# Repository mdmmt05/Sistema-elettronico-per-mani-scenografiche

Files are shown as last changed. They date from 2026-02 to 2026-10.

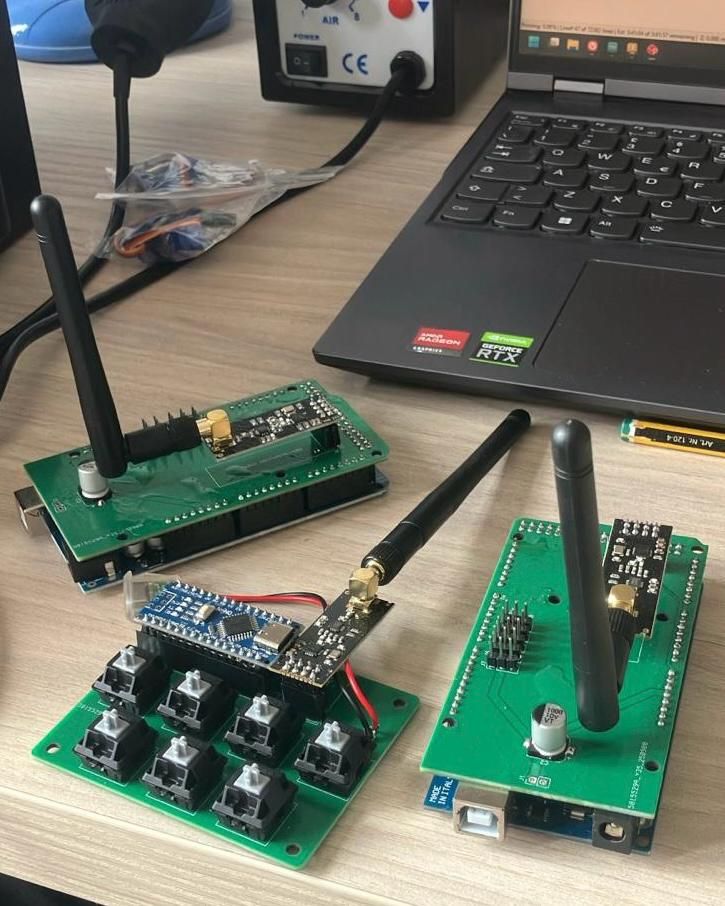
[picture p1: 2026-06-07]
1771791220092.jpeg

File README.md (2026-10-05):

# Nato Due Volte — Scenic Robotic Hands Control System

<div align="center">







</div>

> 🇮🇹 [Italiano](#italiano) · 🇬🇧 [English](#english)

---

# Italiano

## Descrizione

**Nato Due Volte** è un carro carnevalesco presentato alla **73ª edizione del Carnevale di Massafra**. Questa repository documenta il sistema elettronico e firmware realizzato per controllare due **mani scenografiche robotizzate**, ciascuna dotata di cinque dita mosse indipendentemente da servomotori.

Il sistema utilizza un **telecomando palmare personalizzato** che comunica via radio con due unità di controllo indipendenti, una per mano. Ogni unità è basata su Arduino Mega 2560 e su una shield progettata su misura; il telecomando è basato su Arduino Nano con una propria shield dedicata.

## Stato e validazione

Questo progetto è stato **progettato, costruito, programmato, integrato e collaudato fisicamente** per l'impiego sul carro.

A differenza di altri repository presenti nel profilo, la progettazione elettronica, il firmware e l'integrazione sono stati svolti **prevalentemente direttamente dall'autore**, con un approccio hands-on. Il sistema è stato inoltre testato in condizioni operative reali.

Il progetto rappresenta quindi uno dei lavori più direttamente indicativi delle competenze pratiche dell'autore in elettronica embedded, PCB, integrazione hardware-software e collaudo.

## Obiettivi progettuali

I requisiti principali erano:

- controllo indipendente di due mani;
- cinque servomotori per mano;
- comando wireless affidabile;
- interfaccia semplice per un operatore non tecnico;
- installazione e manutenzione semplici durante l'allestimento del carro;
- alimentazione separata e adeguata al carico dei servomotori;
- possibilità di selezionare più sequenze/movimenti per ciascuna mano.

## Architettura

```mermaid
flowchart LR
    OP[Operatore] --> REMOTE[Telecomando
Arduino Nano]
    REMOTE -->|nRF24L01+| CTRL1[Controller mano 1
Arduino Mega]
    REMOTE -->|nRF24L01+| CTRL2[Controller mano 2
Arduino Mega]
    CTRL1 --> S1[5 servomotori]
    CTRL2 --> S2[5 servomotori]
```

Il telecomando consente di inviare fino a **7 comandi di movimento** a ciascuna mano mediante combinazioni di pulsanti.

## Hardware

| Componente | Quantità | Funzione |
|---|---:|---|
| Arduino Mega 2560 | 2 | Unità di controllo delle mani |
| Arduino Nano | 1 | Telecomando |
| nRF24L01+ | 3 | Comunicazione radio |
| Shield personalizzata Mega | 2 | RF, connettori e distribuzione segnali |
| Shield personalizzata Nano | 1 | Pulsanti e modulo RF |
| Servomotori | 10 | Attuazione delle dita |
| Alimentatore 5 V / min. 8 A | 2 | Alimentazione delle mani |
| Powerbank 5 V | 1 | Alimentazione telecomando |

### Collegamento servomotori

| Connettore | Indice firmware | Dito |
|---|---:|---|
| J3 | 0 | Pollice |
| J4 | 1 | Indice |
| J5 | 2 | Medio |
| J6 | 3 | Anulare |
| J7 | 4 | Mignolo |

## Repository

```text
nato-due-volte/
├── controller_code.ino
├── code_telecomando.ino
└── manuale_di_installazione.docx
```

## Installazione firmware

Prerequisiti:

- Arduino IDE;
- libreria RF24.

Per ogni Arduino Mega, impostare `USE_FIRST` in modo coerente con il controller da programmare, quindi caricare `controller_code.ino`. Caricare `code_telecomando.ino` sull'Arduino Nano.

> Caricare entrambe le unità con la stessa configurazione può far rispondere entrambe le mani allo stesso comando.

Per cablaggio, alimentazione e troubleshooting fare riferimento al manuale di installazione.

## Demo

I video `natoduevolte.mp4` e `mano.mp4` mostrano il sistema fisico in funzione.

---

# English

## Project description

**Nato Due Volte** (*Born Twice*) was a carnival float presented at the **73rd edition of the Carnevale di Massafra**. This repository documents the electronics and firmware built to control two **scenic robotic hands**, each with five independently actuated servo-driven fingers.

A custom handheld remote communicates by RF with two independent control units, one for each hand. Each hand controller uses an Arduino Mega 2560 and a custom shield, while the remote uses an Arduino Nano with its own custom shield.

## Status and validation

This project was **designed, built, programmed, integrated, and physically tested** for use on the float.

Unlike some other repositories in this profile, the electronics design, firmware implementation, and system integration were performed **primarily directly by the author** through a hands-on development process. The finished system was tested in real operating conditions.

For that reason, this repository is one of the most representative examples of the author's practical work in embedded electronics, PCB design, hardware-software integration, and field testing.

## Design requirements

The main requirements were:

- independent control of two hands;
- five servos per hand;
- reliable wireless operation;
- simple interaction for a non-technical operator;
- straightforward installation and maintenance;
- adequate power delivery for the servo load;
- multiple selectable motion commands for each hand.

## Architecture

```mermaid
flowchart LR
    OP[Operator] --> REMOTE[Handheld remote
Arduino Nano]
    REMOTE -->|nRF24L01+| CTRL1[Hand controller 1
Arduino Mega]
    REMOTE -->|nRF24L01+| CTRL2[Hand controller 2
Arduino Mega]
    CTRL1 --> S1[5 servos]
    CTRL2 --> S2[5 servos]
```

The remote can send up to **7 motion commands** to each hand through button combinations.

## Hardware

| Component | Qty | Purpose |
|---|---:|---|
| Arduino Mega 2560 | 2 | Hand control units |
| Arduino Nano | 1 | Handheld remote |
| nRF24L01+ | 3 | RF communication |
| Custom Mega shield | 2 | RF and servo interfacing |
| Custom Nano shield | 1 | Buttons and RF interface |
| Servo motors | 10 | Finger actuation |
| 5 V / min. 8 A PSU | 2 | Hand power supply |
| 5 V power bank | 1 | Remote power supply |

## Repository structure

```text
nato-due-volte/
├── controller_code.ino
├── code_telecomando.ino
└── manuale_di_installazione.docx
```

## Firmware installation

Requirements:

- Arduino IDE;
- RF24 library.

Configure `USE_FIRST` appropriately for each Mega controller before uploading `controller_code.ino`. Upload `code_telecomando.ino` to the Arduino Nano.

For wiring, power-supply details, and troubleshooting, see the installation manual.

## Demo

The files `natoduevolte.mp4` and `mano.mp4` show the physical system in operation.

## License

MIT License. See `LICENSE`.

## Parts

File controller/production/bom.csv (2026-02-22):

Designator | Footprint | Quantity | Value | LCSC Part #
A1 | Arduino_Mega2560_R3_Shield | 1 | Arduino_Mega2560_R3_Shield
C1 | 0402 | 1 | 10uF
C2 | CP_Elec_8x10.5 | 1 | 1000uF
C3 | 0402 | 1 | 100nF
J1 | PinHeader_1x02_P2.54mm_Vertical | 1 | PW
J3 | PinHeader_1x03_P2.54mm_Vertical | 1 | Servo1
J4 | PinHeader_1x03_P2.54mm_Vertical | 1 | Servo2
J5 | PinHeader_1x03_P2.54mm_Vertical | 1 | Servo3
J6 | PinHeader_1x03_P2.54mm_Vertical | 1 | Servo4
J7 | PinHeader_1x03_P2.54mm_Vertical | 1 | Servo5
J8 | PinHeader_2x04_P2.54mm_Vertical | 1 | Radio

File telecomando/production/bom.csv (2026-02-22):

Designator | Footprint | Quantity | Value | LCSC Part #
A1 | Arduino_Nano | 1 | Arduino_Nano_v3.x
C1 | 0402 | 1 | 10uF
C2 | 0402 | 1 | 100nF
J1 | PinHeader_1x02_P2.54mm_Vertical | 1 | P_IN
J8 | PinHeader_2x04_P2.54mm_Vertical | 1 | Radio
R3, R4, R5, R6, R7, R8, R9 | 0402 | 7 | 10k
SW1, SW2, SW3, SW4, SW5, SW6, SW7 | SW_Cherry_MX_1.00u_PCB | 7 | SW_Push

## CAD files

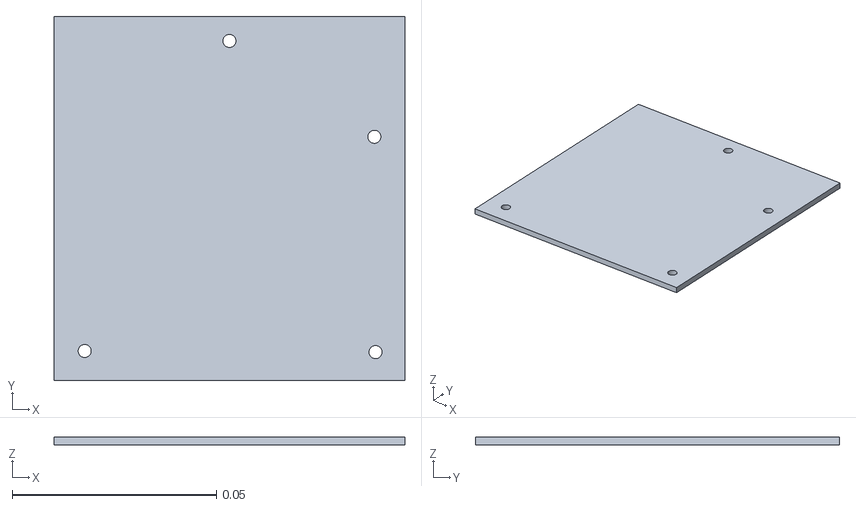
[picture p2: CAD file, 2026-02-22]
telecomando/base.stl
0.086 x 0.0892 x 0.002

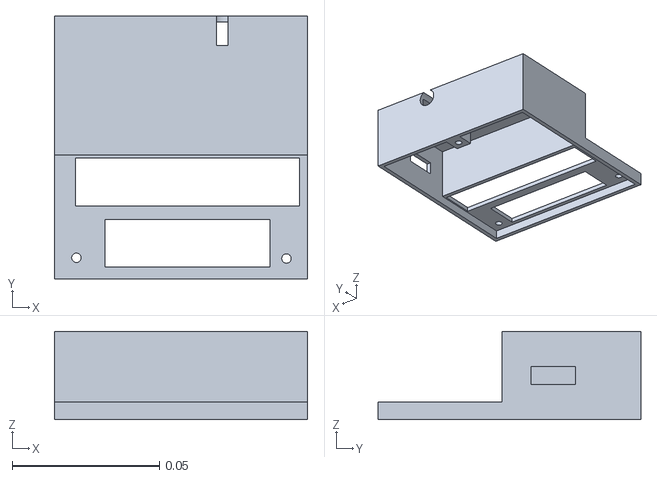
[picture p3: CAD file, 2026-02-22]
telecomando/coperchio.stl
0.086 x 0.0892 x 0.03

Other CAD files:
controller/supporto.ipt
telecomando/Solido1.ipt
telecomando/Solido2.ipt
telecomando/telecomando.iam

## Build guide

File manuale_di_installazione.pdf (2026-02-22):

NATO DUE VOLTE — Installation Manual · Page 1 of 14

# NATO DUE VOLTE

## 73ª edizione del Carnevale di Massafra

# Manuale di Installazione

## Installation Manual

Sistema di controllo delle mani scenografiche robotizzate Robotic Hand Control System

Versione 1.0 · 2025
github.com/mdmmt05/Sistema-elettronico-per-mani-scenografiche

— ITALIANO —

### 1. Introduzione

Il presente documento descrive le istruzioni di installazione e configurazione del sistema di controllo delle mani scenografiche sviluppato per il carro “Nato Due Volte”, presentato alla 73ª edizione del Carnevale di Massafra (Ass. Crazy Events).

Il sistema è composto da due mani scenografiche robotizzate, ciascuna dotata di cinque dita ad attuazione indipendente. Le mani sono gestite da due unità di controllo dedicate e comandate in modalità wireless tramite un telecomando palmare personalizzato.

### 1.1 Panoramica del sistema

Progetto | Nato Due Volte — 73ª edizione Carnevale di Massafra
Sistema | Controllo wireless di mani robotizzate
Unità di controllo | 2 × Arduino Mega 2560 su shield personalizzata
Telecomando | 1 × Arduino Nano su shield personalizzata
Modulo RF | nRF24L01PA+LNA (2,4 GHz, 250 kbps, canale 110)
Attuatori | 5 servomotori per mano (10 in totale)
Firmware | controller_code.ino / code_telecomando.ino

### 1.2 Prerequisiti

Software
- Arduino IDE (qualsiasi versione recente)
- Libreria RF24 — installabile tramite il Library Manager dell’Arduino IDE

Hardware
- 2 × unità di controllo (Arduino Mega + shield personalizzata + nRF24L01+)
- 1 × telecomando (Arduino Nano + shield personalizzata + nRF24L01+)
- 10 × servomotori (5 per mano), con connettore a tre fili (DATA / 5 V / GND)
- 1 × alimentatore regolato 5 V, minimo 5 A, per ciascuna unità di controllo
- 1 × alimentatore regolato 5 V (es. powerbank) per il telecomando

### 2. Telecomando

Il telecomando è il dispositivo diverso dagli altri due nella dotazione. Ospita un Arduino Nano su una shield personalizzata e dispone di sette pulsanti per l’invio dei comandi di movimento alle due unità di controllo.

### 2.1 Identificazione

Il telecomando si identifica come il dispositivo morfologicamente diverso rispetto alle due unità di controllo. Espone una porta USB-C sul lato, utilizzata per l’alimentazione.

### 2.2 Alimentazione

Il telecomando deve essere alimentato tramite la porta USB-C con una sorgente regolata a 5 V (es. powerbank).

⚠ WARNING: Non utilizzare mai una sorgente di alimentazione al di fuori dell’intervallo 4,8 V – 5,2 V. Tensioni superiori a questo limite possono danneggiare irreversibilmente la scheda.

L’alimentazione corretta è confermata dall’accensione di un LED verde in prossimità della porta USB-C.

### 2.3 Layout e indirizzamento dei pulsanti

I sette pulsanti sono indicizzati in ordine di lettura (da sinistra a destra, dall’alto verso il basso), a partire da 0:

[ 0 ] | [ 1 ] | [ 2 ] | [ 3 ]
[ 4 ] | [ 5 ] | [ 6 ]

### 2.4 Protocollo di comunicazione

Un comando viene trasmesso tramite una sequenza di due pressioni:

- La prima pressione seleziona l’indice del comando per il controller #1.
- La seconda pressione seleziona l’indice del comando per il controller #2.
- Le due pressioni devono avvenire entro una finestra di timeout di 2 secondi; se il timeout scade, la sequenza si azzera e la prima pressione deve essere ripetuta.
Il payload trasmesso via radio è una stringa nel formato “primoIndice,secondoIndice” (es. “2,5”). Ciascun controller estrae solo il valore di propria competenza in base al flag USE_FIRST nel proprio firmware (vedere Sezione 4.2).

### 2.5 Antenna RF

L’antenna del telecomando dovrebbe essere orientata verso le unità di controllo per ottimizzare la qualità del segnale. In pratica, grazie alla configurazione radio resistente ai disturbi, un puntamento preciso non è strettamente necessario. La latenza massima attesa tra l’invio del comando e la sua esecuzione sulle unità di controllo è di 75 ms. Ritardi superiori indicano con alta probabilità una trasmissione fallita; in tal caso è sufficiente reinviare il comando.

### 2.6 Smontaggio (se necessario)

Lo smontaggio del telecomando è necessario solo qualora la scheda Arduino Nano interna debba essere riprogrammata.

⚠ WARNING: Devono essere svitate esclusivamente le due viti piccole (M2). La vite più grande è una vite di registro che consente alla piastra inferiore di ruotare attorno al proprio asse per accedere al vano interno — non va rimossa.

### 3. Unità di Controllo (Mani)

Le due unità di controllo sono assiemi identici, ciascuno costituito da un Arduino Mega 2560 montato su una shield personalizzata. Ogni unità aziona una mano robotizzata tramite cinque servomotori e riceve i comandi wireless dal telecomando.

### 3.1 Alimentazione

Ciascuna unità di controllo è alimentata tramite il connettore contrassegnato J1 sulla shield personalizzata. Tale connettore si trova in prossimità del condensatore elettrolitico (grosso cilindro argentato).

Connettore | J1
Pin con simbolo quadrato | GND (massa)
Altro pin | VCC (alimentazione positiva)
Tensione richiesta | 5 V regolati
Corrente minima | 5 A (per garantire sufficiente corrente a tutti e cinque i servomotori simultaneamente)

⚠ WARNING: L’utilizzo di un alimentatore con corrente insufficiente può causare comportamenti anomali dei servomotori o reset del sistema.

### 3.2 Modulo RF e antenna

Il modulo RF nRF24L01+ è montato sulla shield ed è dotato di antenna esterna. Per una ricezione ottimale, l’antenna dovrebbe essere fatta uscire dall’involucro metallico della mano.

Note: Qualora fosse necessario riposizionare l’antenna, è consigliabile spostare solo l’elemento antenna, non l’intero modulo RF, per preservare l’integrità del segnale.

### 3.3 Collegamento dei servomotori

I servomotori vanno collegati ai connettori da J3 a J7 sulla shield. L’ordine di cablaggio è indicato a lato di ciascun connettore sulla shield stessa:

DATA | — | 5 V | — | GND

L’indice del servomotore nel firmware corrisponde direttamente all’etichetta del connettore:

Connector (shield) | Servo index (firmware) | Finger
J3 | 0 | Pollice
J4 | 1 | Indice
J5 | 2 | Medio
J6 | 3 | Anulare
J7 | 4 | Mignolo

Note: L’indice 0 corrisponde al primo dito attuato (pollice); gli indici aumentano in sequenza attraverso la mano.

### 4. Software

### 4.1 Panoramica dei file

controller_code.ino | Firmware per le due unità di controllo (Arduino Mega).
code_telecomando.ino | Firmware per il telecomando (Arduino Nano).

### 4.2 Caricamento del firmware sulle unità di controllo

Entrambe le unità di controllo utilizzano lo stesso file sorgente (controller_code.ino). La costante preprocessore USE_FIRST determina quale valore della stringa di comando ricevuta ciascuna unità deve elaborare:

Controller #1 | #define USE_FIRST true
Controller #2 | #define USE_FIRST false

⚠ WARNING: Questo flag deve essere impostato correttamente prima di caricare il firmware su ciascuna scheda. Caricare entrambe le schede con lo stesso valore causerà la risposta di entrambe le mani allo stesso pulsante.

Procedura di caricamento:

- Aprire controller_code.ino nell’Arduino IDE.
- Impostare USE_FIRST con il valore appropriato per la scheda di destinazione.
- Selezionare “Arduino Mega or Mega 2560” come scheda target.
- Caricare lo sketch.
- Ripetere la procedura per la seconda scheda con il valore opposto di USE_FIRST.

### 4.3 Caricamento del firmware sul telecomando

Aprire code_telecomando.ino nell’Arduino IDE, selezionare “Arduino Nano” come scheda target e caricare lo sketch. Non è richiesta alcuna configurazione aggiuntiva.

### 4.4 Struttura della mappa dei comandi

Il firmware memorizza 7 sequenze di movimento predefinite (una per pulsante) nell’array commandMaps. Ogni comando è composto da un array ordinato di Step, un contatore numSteps e un flag repeat.

Ciascuno Step è definito dai seguenti campi:

Field | Type | Description
servoIndex | int (0–4) | Index of the servo motor to move.
targetAngle | int (°) | Target position in degrees.
time | ulong (ms) | Duration of the movement (interpolated) or minimum settling time (natural).

Field | Type | Description
pause | ulong (ms) | Delay after this step before the next begins. A non-zero value also terminates the current synchronised group.
useInterpolation | bool | true: linear interpolation over time. false: full-speed snap to target.

Gruppi sincronizzati
Gli step vengono raggruppati automaticamente dal firmware. Step consecutivi con pause == 0 vengono eseguiti in parallelo (tutti i movimenti del gruppo partono simultaneamente). Uno step con pause > 0 termina il gruppo corrente: tutti i movimenti del gruppo vengono completati, dopodiché trascorre la pausa specificata prima dell’inizio del gruppo successivo.

Modifica di un comando
Per modificare un comando esistente o aggiungerne uno nuovo, è necessario modificare la voce corrispondente in commandMaps:
- Aggiungere o rimuovere elementi Step all’interno delle parentesi graffe.
- Aggiornare il valore intero numSteps affinché corrisponda al numero effettivo di step nell’array.
- Impostare il booleano repeat a true se il comando deve ripetersi in loop fino all’arrivo di un nuovo comando, o a false per un’esecuzione singola.
- Qualsiasi comando in arrivo interrompe immediatamente quello in esecuzione.

Note: Angoli di step al di fuori dell’escursione fisica del servomotore (tipicamente 0–270°) verranno limitati dalla libreria servo. Si raccomanda di validare i nuovi movimenti a bassa velocità prima dell’utilizzo in condizioni di esibizione.

### 5. Riferimento Rapido

### 5.1 Lista di verifica pre-installazione

- Alimentatori verificati: 5 V / 5 A per ciascuna unità di controllo, 5 V per il telecomando.
- controller_code.ino caricato con USE_FIRST corretto su ciascun Mega.
- code_telecomando.ino caricato sul Nano.
- Tutti i connettori dei servomotori inseriti negli slot corretti (J3–J7).
- Antenne RF portate all’esterno degli involucri metallici.
- LED verde sul telecomando acceso all’accensione.

### 5.2 Risoluzione dei problemi

Il telecomando non si
accende

Verificare la sorgente di alimentazione USB-C. Controllare che la tensione sia compresa tra 4,8 e 5,2 V.

Comando non ricevuto dall’unità di controllo | Reinviare il comando. Assicurarsi che le due pressioni avvengano entro il timeout di 2 s. Verificare l’orientamento dell’antenna RF.
La mano sbagliata risponde a un pulsante | Verificare che USE_FIRST sia impostato correttamente su ciascuna unità di controllo e ricaricare il firmware se necessario.
Il servo si porta in posizione errata | Controllare l’orientamento del connettore del servo (DATA / 5 V / GND). Verificare l’assegnazione J3–J7.
Movimento anomalo / reset del sistema | Corrente dell’alimentatore insufficiente. Utilizzare un alimentatore con corrente minima di 8 A.
Ritardo tra pressione e movimento della mano | Atteso: fino a 75 ms. Se sistematicamente superato, verificare la presenza di interferenze RF o pressione insufficiente sui pulsanti.

— ENGLISH —

### 1. Introduction

This document provides the installation and configuration instructions for the robotic hand control system developed for the float “Nato Due Volte,” presented at the 73rd edition of the Carnevale di Massafra.

The system consists of two scenic robotic hands, each equipped with five independently actuated fingers. The hands are driven by two dedicated control units and operated wirelessly via a custom handheld remote controller.

### 1.1 System overview

Project | Nato Due Volte — 73rd Carnevale di Massafra
System | Wireless robotic hand control
Control units | 2 × Arduino Mega 2560 on custom shield
Remote | 1 × Arduino Nano on custom shield
RF module | nRF24L01+ (2.4 GHz, 250 kbps, channel 110)
Actuators | 5 servo motors per hand (10 total)
Firmware | controller_code.ino / code_telecomando.ino

### 1.2 Prerequisites

Software
- Arduino IDE (any recent version)
- RF24 library — installable via the Arduino IDE Library Manager

Hardware
- 2 × control unit assembly (Arduino Mega + custom shield + nRF24L01+)
- 1 × remote controller assembly (Arduino Nano + custom shield + nRF24L01+)
- 10 × servo motors (5 per hand), with three-wire connectors (DATA / 5 V / GND)
- 1 × regulated 5 V power supply, minimum 5 A, for each control unit
- 1 × regulated 5 V power supply (e.g. powerbank) for the remote controller

### 2. Remote Controller

The remote controller is the unique device in the kit. It hosts an Arduino Nano on a custom shield and provides seven push-buttons for sending movement commands to the two control units.

### 2.1 Identification

The remote controller can be identified as the device that differs from the other two. It exposes a USB-C port on its side, used for power supply.

### 2.2 Power supply

The remote controller must be powered via its USB-C port with a regulated 5 V source (e.g. a powerbank).

⚠ WARNING: Never use a power source outside the 4.8 V – 5.2 V range. Voltages above this threshold may permanently damage the board.

Correct power delivery is confirmed by a green LED illuminating near the USB-C port.

### 2.3 Button layout and addressing

The seven buttons are indexed in reading order (left to right, top to bottom), starting from 0:

[ 0 ] | [ 1 ] | [ 2 ] | [ 3 ]
[ 4 ] | [ 5 ] | [ 6 ]

### 2.4 Communication protocol

A command is transmitted using a two-press sequence:

- The first button press selects the command index for controller #1.
- The second button press selects the command index for controller #2.
- The two presses must occur within a 2-second timeout window; if the window expires, the sequence resets and the first press must be repeated.
The payload sent over the air is a comma-separated string of the form “firstIndex,secondIndex” (e.g. “2,5”). Each controller extracts only the value relevant to it based on the USE_FIRST flag in its firmware (see Section 4.2).

### 2.5 RF antenna

The antenna protruding from the remote controller should be oriented towards the control units for optimal signal strength. In practice, due to the noise-resistant radio configuration, precise pointing is not strictly required. A maximum latency of 75 ms is expected between command transmission and execution on the control units. Delays exceeding this threshold most likely indicate a failed transmission; the command should be resent in that case.

### 2.6 Disassembly (if required)

Disassembly of the remote controller is required only if the internal Arduino Nano board needs to be reprogrammed.

⚠ WARNING: Only the two small M2 screws must be removed. The larger screw is a pivot that allows the bottom plate to rotate and expose the internal compartment — do not unscrew it.

### 3. Control Units (Hands)

The two control units are identical assemblies, each consisting of an Arduino Mega 2560 mounted on a custom shield. Each unit drives one robotic hand via five servo motors and receives wireless commands from the remote controller.

### 3.1 Power supply

Each control unit is powered through the connector labelled J1 on the custom shield. This connector is located near the electrolytic capacitor (large silver cylindrical component).

Connector | J1
Square-marked pin | GND (ground)
Other pin | VCC (positive supply)
Required voltage | 5 V regulated
Minimum current | 5 A (to ensure adequate power to all five servo motors simultaneously)

⚠ WARNING: Using a power supply with insufficient current rating may cause erratic servo behaviour or system resets.

### 3.2 RF module and antenna

The nRF24L01+ RF module is mounted on the shield and is fitted with an external antenna. For optimal reception, the antenna should be routed outside the metallic enclosure of the hand.

Note: If repositioning of the antenna is required, only the antenna element itself should be relocated. Moving the entire RF module may compromise signal integrity.

### 3.3 Servo motor connections

Servo motors are connected to the connectors labelled J3 through J7 on the shield. The wiring order is printed on the shield next to each connector:

DATA | — | 5 V | — | GND

The servo index in the firmware corresponds directly to the connector label:

Connector (shield) | Servo index (firmware) | Finger
J3 | 0 | Thumb
J4 | 1 | Index
J5 | 2 | Middle
J6 | 3 | Ring
J7 | 4 | Little

Note: Servo index 0 corresponds to the first activated finger (thumb); indices increase sequentially across the hand.

### 4. Software

### 4.1 File overview

controller_code.ino | Firmware for the two control units (Arduino Mega).
code_telecomando.ino | Firmware for the remote controller (Arduino Nano).

### 4.2 Flashing the control units

Both control units use the same source file (controller_code.ino). The USE_FIRST preprocessor constant determines which value from the received command string each unit responds to:

Controller #1 | #define USE_FIRST true
Controller #2 | #define USE_FIRST false

⚠ WARNING: This flag must be set correctly before flashing each board. Flashing both boards with the same value will cause both hands to respond to the same button press.

To flash a control unit:

- Open controller_code.ino in the Arduino IDE.
- Set USE_FIRST to the appropriate value for the target board.
- Select “Arduino Mega or Mega 2560” as the board.
- Upload the sketch.
- Repeat for the second board with the opposite USE_FIRST value.

### 4.3 Flashing the remote controller

Open code_telecomando.ino in the Arduino IDE, select “Arduino Nano” as the board, and upload the sketch. No configuration is required.

### 4.4 Command map structure

The firmware stores 7 pre-defined movement sequences (one per button) in the commandMaps array. Each command consists of an ordered array of Steps, a step count (numSteps), and a repeat flag.

Each Step is defined by the following fields:

Field | Type | Description
servoIndex | int (0–4) | Index of the servo motor to move.
targetAngle | int (°) | Target position in degrees.
time | ulong (ms) | Duration of the movement (interpolated) or minimum settling time (natural).
pause | ulong (ms) | Delay after this step before the next begins. A non-zero value also terminates the current synchronised group.

Field | Type | Description
useInterpolation | bool | true: linear interpolation over time. false: full-speed snap to target.

Synchronised groups
Steps are grouped automatically by the firmware. Consecutive steps with pause == 0 are executed in parallel (all servo movements in the group start simultaneously). A step with pause > 0 terminates the current group, all movements in the group complete, and the specified pause elapses before the next group begins.

Modifying a command
To modify an existing command or add a new one, edit the corresponding entry in commandMaps:
- Add or remove Step entries within the braces.
- Update the numSteps integer to match the actual number of steps in the array.
- Set the repeat boolean to true if the command should loop until interrupted, or false for single execution.
- Any incoming command immediately interrupts the currently executing one.

Note: Step angles outside the physical servo range (typically 0–270°) will be clamped by the servo library. Validate new movements at low speed before use in performance conditions.

### 5. Quick Reference

### 5.1 Pre-installation checklist

- Power supplies verified: 5 V / 5 A for each control unit, 5 V for remote.
- controller_code.ino flashed with correct USE_FIRST on each Mega.
- code_telecomando.ino flashed on the Nano.
- All servo connectors inserted in correct J3–J7 slots.
- RF antennas routed outside metallic enclosures.
- Green LED on remote controller illuminated at power-on.

### 5.2 Troubleshooting

Remote controller does
not power on

Check USB-C power source. Verify voltage is within 4.8– 5.2 V.

Command not received by control unit | Re-send the command. Ensure both button presses occur within the 2 s timeout. Check RF antenna orientation.
Wrong hand responds to a button | Verify USE_FIRST is set correctly on each control unit and re-flash if necessary.
Servo moves to incorrect position | Check servo connector orientation (DATA / 5 V / GND). Verify J3–J7 assignment.
Erratic servo movement / system resets | Insufficient power supply current. Use a supply rated at a minimum of 5 A.
Latency between press and hand movement | Expected: up to 75 ms. If consistently exceeded, check for RF interference or insufficient button press duration.

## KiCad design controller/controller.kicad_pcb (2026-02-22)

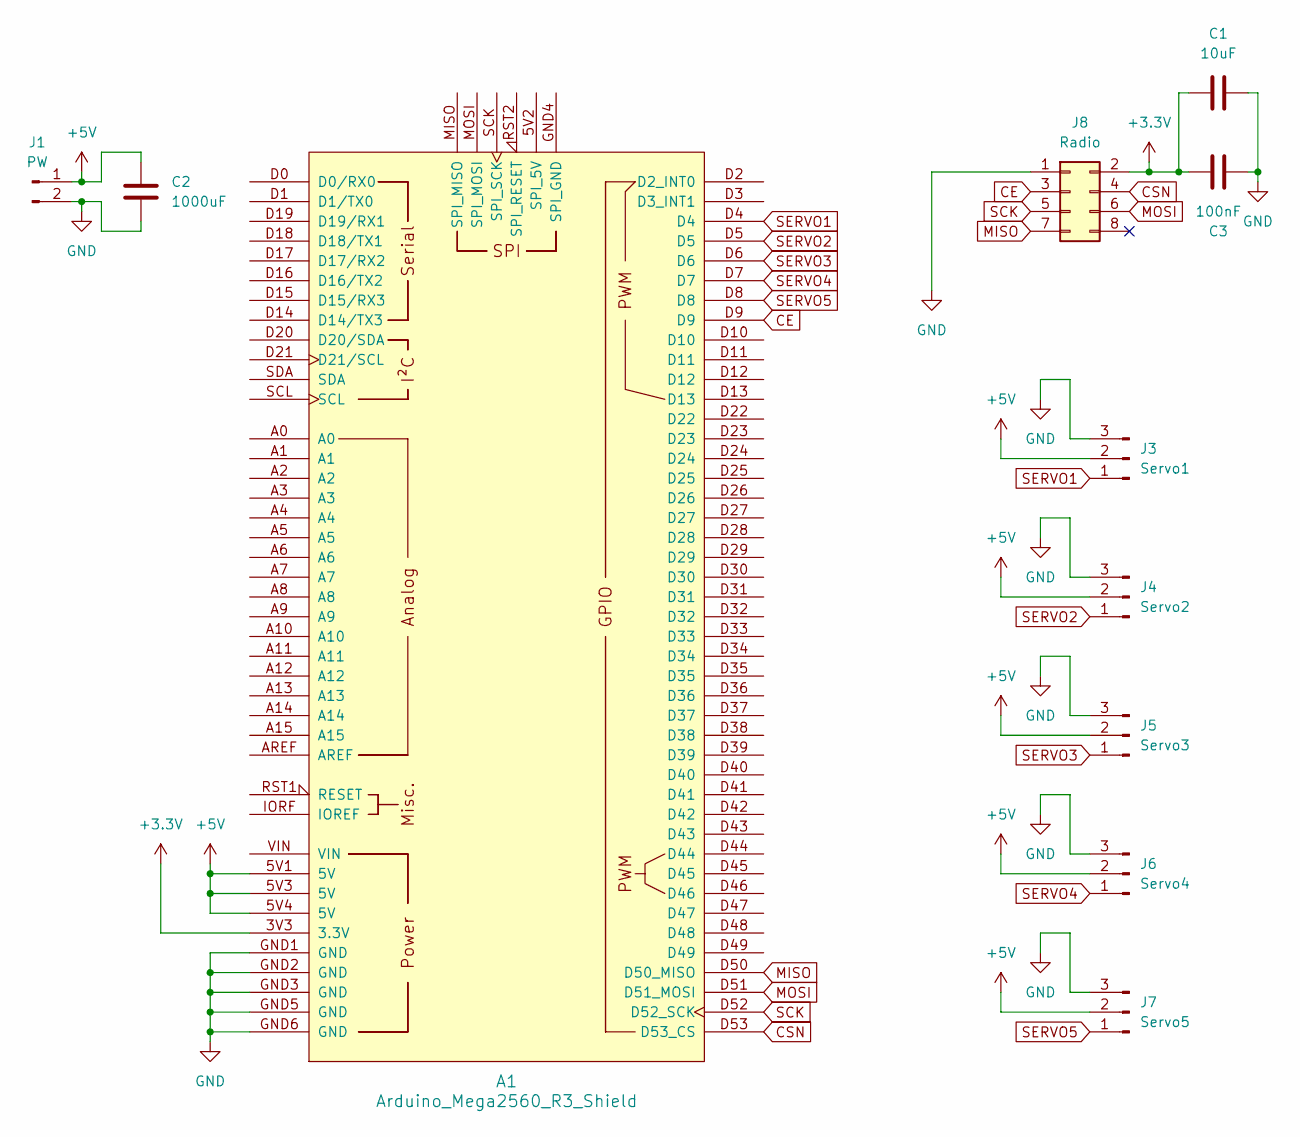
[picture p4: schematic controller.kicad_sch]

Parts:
A1: Arduino_Mega2560_R3_Shield
C1: 10uF; C_0402_1005Metric_Pad0.74x0.62mm_HandSolder
C2: 1000uF; CP_Elec_8x10.5
C3: 100nF; C_0402_1005Metric_Pad0.74x0.62mm_HandSolder
J1: PW; PinHeader_1x02_P2.54mm_Vertical
J3: Servo1; PinHeader_1x03_P2.54mm_Vertical
J4: Servo2; PinHeader_1x03_P2.54mm_Vertical
J5: Servo3; PinHeader_1x03_P2.54mm_Vertical
J6: Servo4; PinHeader_1x03_P2.54mm_Vertical
J7: Servo5; PinHeader_1x03_P2.54mm_Vertical
J8: Radio; PinHeader_2x04_P2.54mm_Vertical

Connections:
+3.3V: A1.3V3 (3.3V), C1.1, C3.2, J8.2
+5V: A1.5V1 (5V), A1.5V3 (5V), A1.5V4 (5V), C2.2, J1.1, J3.2, J4.2, J5.2, J6.2, J7.2
CE: A1.D9, J8.3
CSN: A1.D53 (D53_CS), J8.4
GND: A1.GND1 (GND), A1.GND2 (GND), A1.GND3 (GND), A1.GND5 (GND), A1.GND6 (GND), C1.2, C2.1, C3.1, J1.2, J3.3, J4.3, J5.3, J6.3, J7.3, J8.1
MISO: A1.D50 (D50_MISO), J8.7
MOSI: A1.D51 (D51_MOSI), J8.6
SCK: A1.D52 (D52_SCK), J8.5
SERVO1: A1.D4, J3.1
SERVO2: A1.D5, J4.1
SERVO3: A1.D6, J5.1
SERVO4: A1.D7, J6.1
SERVO5: A1.D8, J7.1

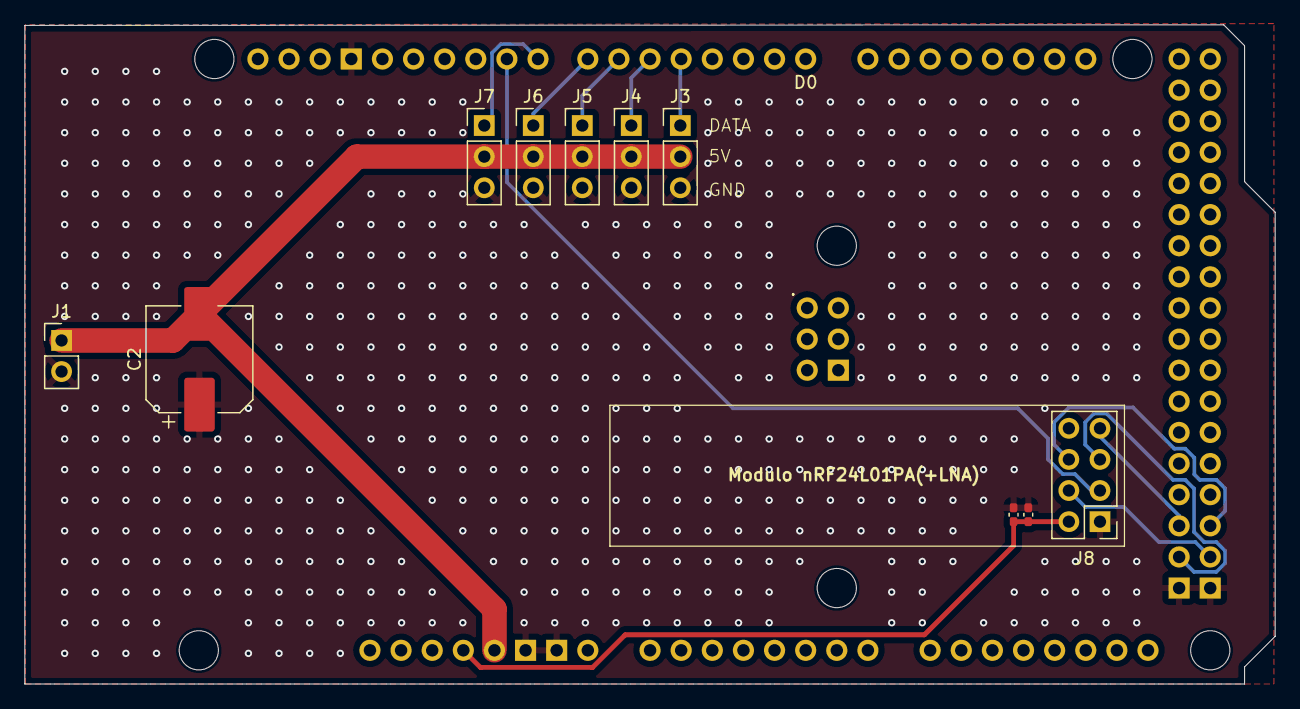
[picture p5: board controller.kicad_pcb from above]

Board: 2 copper layers, 102.1 x 53.8 mm, 11 parts (0 on the bottom side), 13 nets.

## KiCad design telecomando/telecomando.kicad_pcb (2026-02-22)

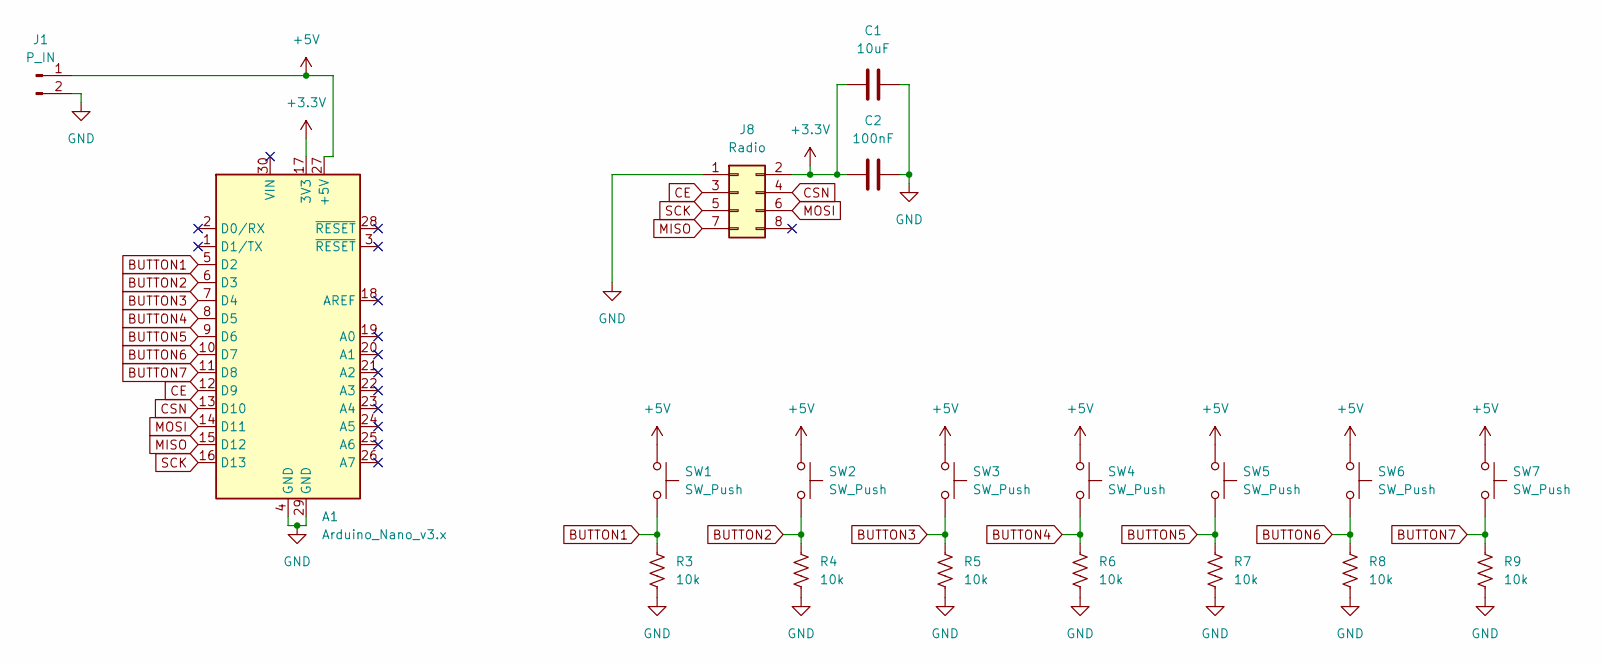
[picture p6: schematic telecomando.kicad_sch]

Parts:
A1: Arduino_Nano_v3.x; Arduino_Nano
C1: 10uF; C_0402_1005Metric_Pad0.74x0.62mm_HandSolder
C2: 100nF; C_0402_1005Metric_Pad0.74x0.62mm_HandSolder
J1: P_IN; PinHeader_1x02_P2.54mm_Vertical
J8: Radio; PinHeader_2x04_P2.54mm_Vertical
R3, R4, R5, R6, R7, R8, R9: 10k; R_0402_1005Metric_Pad0.72x0.64mm_HandSolder
SW1, SW2, SW3, SW4, SW5, SW6, SW7: SW_Push; SW_Cherry_MX_1.00u_PCB

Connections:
+3.3V: A1.17 (3V3), C1.1, C2.1, J8.2
+5V: A1.27 (+5V), J1.1, SW1.1, SW2.1, SW3.1, SW4.1, SW5.1, SW6.1, SW7.1
BUTTON1: A1.5 (D2), R3.1, SW1.2
BUTTON2: A1.6 (D3), R4.1, SW2.2
BUTTON3: A1.7 (D4), R5.1, SW3.2
BUTTON4: A1.8 (D5), R6.1, SW4.2
BUTTON5: A1.9 (D6), R7.1, SW5.2
BUTTON6: A1.10 (D7), R8.1, SW6.2
BUTTON7: A1.11 (D8), R9.1, SW7.2
CE: A1.12 (D9), J8.3
CSN: A1.13 (D10), J8.4
GND: A1.4 (GND), A1.29 (GND), C1.2, C2.2, J1.2, J8.1, R3.2, R4.2, R5.2, R6.2, R7.2, R8.2, R9.2
MISO: A1.15 (D12), J8.7
MOSI: A1.14 (D11), J8.6
SCK: A1.16 (D13), J8.5

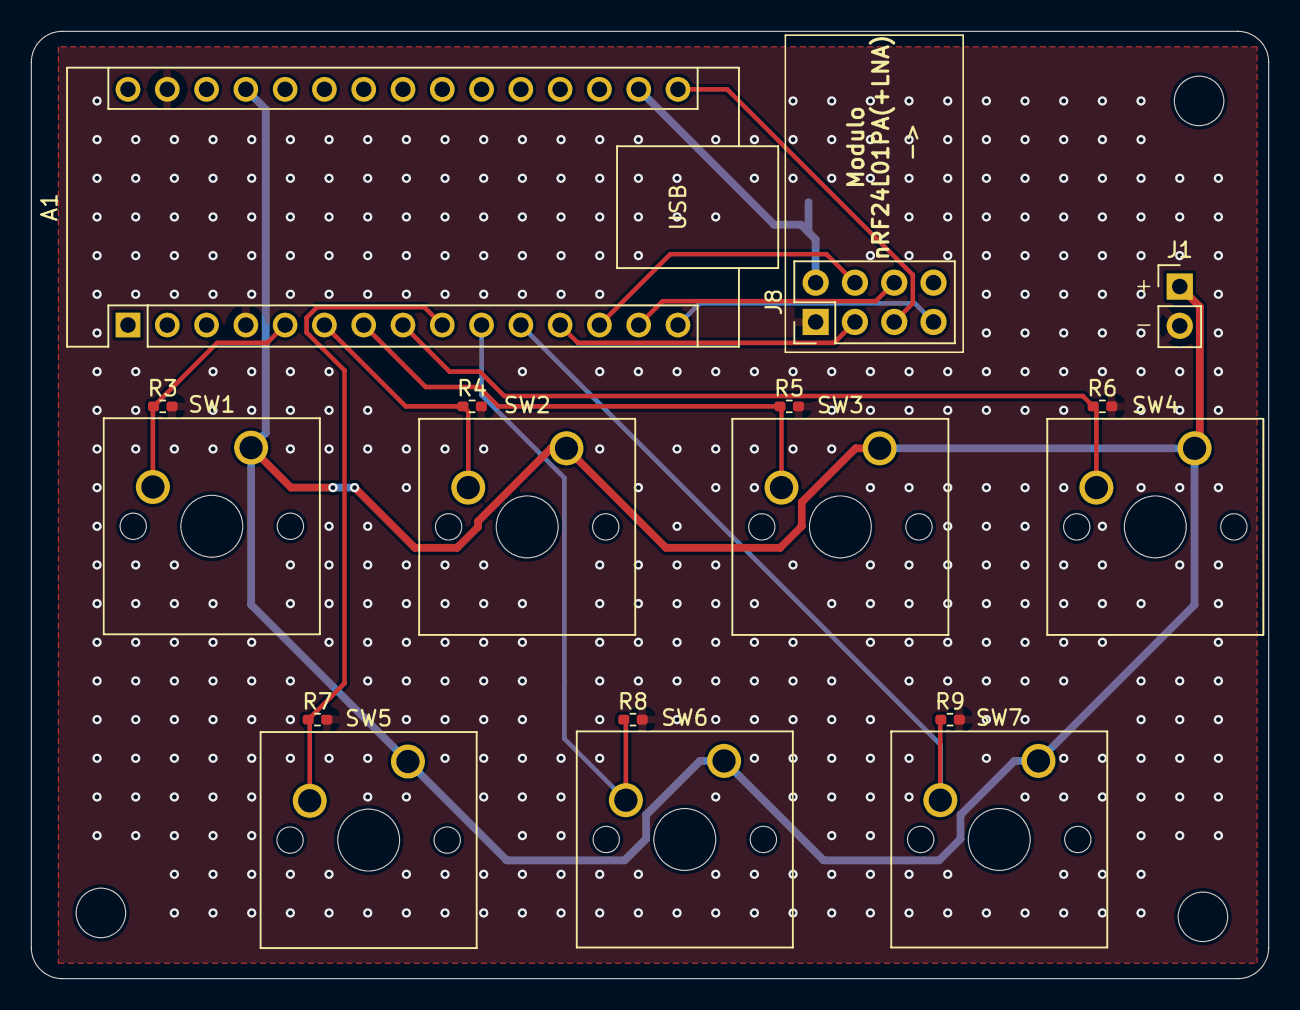
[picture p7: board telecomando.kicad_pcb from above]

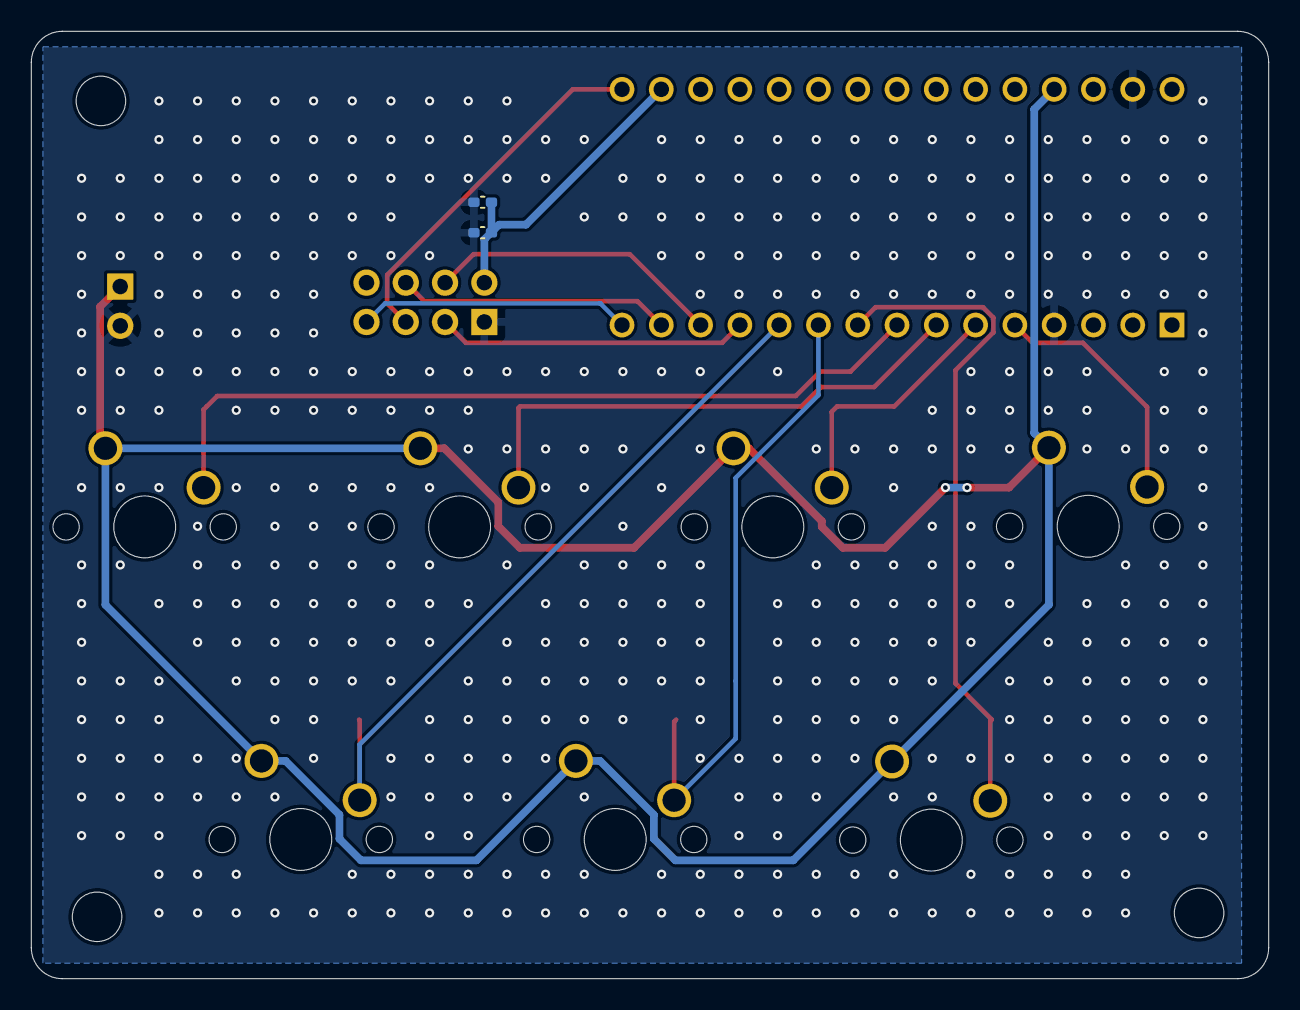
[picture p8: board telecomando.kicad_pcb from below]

Board: 2 copper layers, 80.0 x 61.2 mm, 19 parts (2 on the bottom side), 15 nets.

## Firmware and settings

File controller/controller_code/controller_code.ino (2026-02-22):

/**
 * @file    controller_code.ino
 * @brief   Control unit firmware for the "Nato Due Volte" carnival float
 *          (73rd edition of the Carnevale di Massafra).
 *
 * This sketch runs on a custom Arduino Mega shield and controls a scenic
 * robotic hand composed of 5 servo motors. Two identical units are used
 * (one per hand); they receive wireless commands from a shared remote
 * controller (see code_telecomando.ino) via the nRF24L01+ module.
 *
 * Communication protocol:
 *   Commands arrive as comma-separated strings "firstButton,secondButton".
 *   USE_FIRST determines which value this unit responds to:
 *     - Controller #1: set USE_FIRST to true
 *     - Controller #2: set USE_FIRST to false
 *
 * ┌─────────────────────────────────────────────────────────────────┐
 * │  IMPORTANT: set USE_FIRST correctly before flashing each board  │
 * └─────────────────────────────────────────────────────────────────┘
 *
 * Each command maps to a sequence of servo movements ("steps") grouped
 * into a Command structure. Steps with no pause (pause == 0) are grouped
 * and executed simultaneously; a non-zero pause value terminates a group
 * and introduces a delay before the next one begins.
 *
 * Hardware:
 *   - Arduino Mega 2560 (on custom shield)
 *   - nRF24L01+ transceiver module  (CE: pin 9, CSN: pin 53)
 *   - 5 servo motors                (signal pins: 4, 5, 6, 7, 8)
 *
 * Dependencies:
 *   - RF24 library (available via Arduino IDE Library Manager)
 */

#include <SPI.h>
#include <nRF24L01.h>
#include <RF24.h>
#include <Servo.h>

// --- RF24 configuration ---
#define CE_PIN 9
#define CSN_PIN 53
RF24 radio(CE_PIN, CSN_PIN);
const byte address[6] = "00001";

// --- Servo configuration ---
#define NUM_SERVOS 5
Servo servos[NUM_SERVOS];
int servoPins[NUM_SERVOS] = {4, 5, 6, 7, 8};

// ┌─────────────────────────────────────────────────────────────────┐
// │  Set to true for controller #1, false for controller #2         │
// └─────────────────────────────────────────────────────────────────┘
#define USE_FIRST false

// --- Data structures ---

/**
 * @brief A single movement instruction for one servo.
 *
 * @param servoIndex       Index of the target servo (0–4).
 * @param targetAngle      Target position in degrees.
 * @param time             Duration of the movement in milliseconds.
 * @param pause            Delay after this step before the next one (ms).
 *                         A non-zero value also terminates the current
 *                         synchronised group.
 * @param useInterpolation If true, the servo moves with linear interpolation
 *                         over the specified duration; if false, it jumps
 *                         directly to the target at full speed.
 */
struct Step {
  int servoIndex;
  int targetAngle;
  unsigned long time;
  unsigned long pause;
  bool useInterpolation;
};

/**
 * @brief A complete command, consisting of an ordered sequence of Steps.
 *
 * @param steps    Array of up to 20 steps.
 * @param numSteps Number of active steps in the array.
 * @param repeat   If true, the command loops until a new one is received.
 */
struct Command {
  Step steps[20];
  int numSteps;
  bool repeat;
};

// ---------------------------------------------------------------------------
// Command map — 7 commands (one per remote button, indexed 0–6)
// ---------------------------------------------------------------------------
Command commandMaps[7] = {
  // ---- Command 0: all servos to 0° (reset position) ----
  {
    {
      {0, 0, 2000, 0, true},  
      {1, 0, 2000, 0, true},  
      {2, 0, 2000, 0, true}, 
      {3, 0, 2000, 0, true},
      {4, 0, 2000, 10, true},
    },
    5,
    false
  },
  // ---- Command 1 ----
  {
    {
      {0,   0, 2000,  0, true},
      {1, 250, 1500,  0, true},
      {2,   0, 1500,  0, true},
      {3,   0, 1500,  0, true},  
      {4, 180, 2000, 10, true}
    },
    5,
    false
  },
  // ---- Command 2 ----
  {
    {
      {0,   0, 2000,   0, true},
      {1,   0, 2000,   0, true},
      {2, 260, 2000,   0, true},
      {3,  0,  2000,   0, true},
      {4,  0,  500,  10, true}
    },
    5,
    false
  },
  // ---- Command 3 (looping) ----
  {
    {
      {0, 140, 2000,  0, true},
      {1, 260, 2000,  0, true},
      {2, 260, 2000,  0, true},
      {3, 250, 2000,  0, true},
      {4, 180, 2000, 1000, true},
      {0, 0, 1500,    0, true},
      {1, 0, 1500,    0, true},
      {2, 0, 1500,    0, true},
      {3, 0, 1500,    0, true},
      {4, 0, 1500, 1000, true},
    },
    10,
    true
  },
  // ---- Comando 4 (looping) ----
  {
    {
      {0, 140,  2000, 0, true},
      {1, 260,  2000, 0, true},
      {2, 260,  2000, 0, true},
      {3, 250,  2000, 0, true},
      {4, 180,  2000, 1000, true},
      {0, 140,  1500, 0, true},
      {1, 200,  1500, 0, true},
      {2, 220,  1500, 0, true},
      {3, 210,  1500, 0, true},
      {4, 130,  1500, 1000, true},
    },
    10,
    true
  },
  // ---- Comando 5 (looping) ----
  {
    {
      {0, 0,   1200, 200, true},
      {1, 180, 1200, 200, true},
      {2, 0,   1200, 200, true},
      {3, 180, 1200, 200, true},
      {4, 90,  1000, 0, true}
    },
    5,
    true
  },
  // ---- Comando 6 (no interpolation - snap to position) ----
  {
    {
      {0, 30,  600, 100, false},
      {1, 60,  600, 100, false},
      {2, 120, 600, 100, false},
      {3, 150, 600, 100, false},
      {4, 180, 600, 0, false}
    },
    5,
    false
  }
};

// ---------------------------------------------------------------------------
// Global state
// ---------------------------------------------------------------------------
volatile int currentCommand = -1; // last received command index
volatile bool newCommand    = false;

// ---------------------------------------------------------------------------
// Radio helpers
// ---------------------------------------------------------------------------

/**
 * @brief Check the radio for an incoming command without blocking.
 *        Updates currentCommand and sets newCommand = true if a valid
 *        command is received. Safe to call during command execution.
 * @return true if a new command was received, false otherwise.
 */
static inline bool pollRadioAndUpdate() {
  if (radio.available()) {
    char text[32] = {0};
    radio.read(&text, sizeof(text));

    int firstNum = 0, secondNum = 0;
    sscanf(text, "%d,%d", &firstNum, &secondNum);
    int receivedNumber = USE_FIRST ? firstNum : secondNum;

    if (receivedNumber >= 0 && receivedNumber <= 6) {
      Serial.print("New comamnd received during execution: ");
      Serial.println(receivedNumber);
      currentCommand = receivedNumber;
      newCommand = true;
      return true;
    }
  }
  return false;
}

/**
 * @brief Blocking delay that can be interrupted by an incoming command.
 *        Returns early if a new command is detected via pollRadioAndUpdate().
 * @param ms Duration in milliseconds.
 */
static inline void cancellableDelay(unsigned long ms) {
  unsigned long endAt = millis() + ms;
  while ((long)(endAt - millis()) > 0) {
    // Se arriva un nuovo comando, usciamo subito
    if (pollRadioAndUpdate() || newCommand) return;
    delay(1);
  }
}

/** @brief Convenience macro: poll radio and return from caller if interrupted. */
#define CHECK_CANCEL() do { if (pollRadioAndUpdate() || newCommand) return; } while (0)

// ---------------------------------------------------------------------------
// Movement helpers
// ---------------------------------------------------------------------------

/**
 * @brief Internal state for one servo during a synchronised group movement.
 */
struct ServoMovement{
  int servoIndex;
  int startAngle;
  int targetAngle;
  unsigned long duration;
  bool useInterpolation;
  bool active;
};

// ---------------------------------------------------------------------------
// Command execution
// ---------------------------------------------------------------------------

/**
 * @brief Execute the command at the given index.
 *        Steps are grouped by their pause value: consecutive steps with
 *        pause == 0 are executed simultaneously; a step with pause > 0
 *        terminates the group and waits before the next group begins.
 *        The function returns immediately if a new command is received.
 * @param cmdIndex Index into commandMaps (0–6).
 */
void executeCommand(int cmdIndex) {
  Command cmd = commandMaps[cmdIndex];
  int loopNum = 0;

  do {
    int i = 0;
    while (i < cmd.numSteps){
      // --- Determine the extent of the current group ---
      int groupStart = i;
      int groupEnd = i;

      while (groupEnd < cmd.numSteps) {
        groupEnd++;
        if (groupEnd <= cmd.numSteps && cmd.steps[groupEnd - 1].pause != 0) {
          break;
        }
      }

      int groupSize = groupEnd - groupStart;

      // ---------------------------------------------------------------
      // Single-step group
      // ---------------------------------------------------------------
      if (groupSize == 1) {
        Step s = cmd.steps[i];

        Serial.print(">>> Single step ");
        Serial.print(i);
        Serial.print(": servo ");
        Serial.print(s.servoIndex);
        Serial.print(" -> ");
        Serial.print(s.targetAngle);
        Serial.print(" deg in ");
        Serial.print(s.time);
        Serial.println(" ms");

        if (s.useInterpolation){
          int startAngle = servos[s.servoIndex].read();
          unsigned long startTime = millis();

          while (millis() - startTime < s.time) {
            float progress = float(millis() - startTime) / s.time;
            int angle = startAngle + (s.targetAngle - startAngle) * progress;
            servos[s.servoIndex].write(angle);
            cancellableDelay(15);
            CHECK_CANCEL();
          }

          servos[s.servoIndex].write(s.targetAngle);
          Serial.println("Interpolated step done: " + String(i));
        } else {
          // snap to target at full servo speed
          servos[s.servoIndex].write(s.targetAngle);
          Serial.println("Natural step done: " + String(i));
          cancellableDelay(15); // allow the command to reach the servo
          CHECK_CANCEL();
        }
      
        if (s.pause > 0) {
            Serial.println(">>> Pause: " + String(s.pause) + " ms");
        }

        cancellableDelay(s.pause);
        if (newCommand) return;

        i++;
      // ---------------------------------------------------------------
      // Synchronised group (multiple servos moving in parallel)
      // ---------------------------------------------------------------
      } else {
        Serial.println("Executing synchronised group: steps  " + String(groupStart) + " to " + String(groupEnd - 1));
        
        ServoMovement movements[20];
        unsigned long maxDuration = 0;
        unsigned long finalPause = cmd.steps[groupEnd - 1].pause;
        bool anyInterpolated = false;
        
        // Prepare movement data for each servo in the group
        for (int j = 0; j < groupSize; j++) {
          Step s = cmd.steps[groupStart + j];
          movements[j].servoIndex = s.servoIndex;
          movements[j].startAngle = servos[s.servoIndex].read();
          movements[j].targetAngle = s.targetAngle;
          movements[j].duration = s.time;
          movements[j].useInterpolation = s.useInterpolation;
          movements[j].active = true;
          
          if (s.useInterpolation) {
            anyInterpolated = true;
            if (s.time > maxDuration) {
              maxDuration = s.time;
            }
          }
        }

        if (!anyInterpolated) {
          // All steps are natural: snap every servo simultaneously
          for (int j = 0; j < groupSize; j++) {
            servos[movements[j].servoIndex].write(movements[j].targetAngle);
          }
          Serial.println("Natural group executed instantly.");
          cancellableDelay(15);
        }
        else {
          // Drive all servos concurrently with per-servo interpolation
          unsigned long startTime = millis();
          unsigned long lastUpdate = 0;          

          while (millis() - startTime < maxDuration) {
            CHECK_CANCEL();
            
            unsigned long elapsed = millis() - startTime;
            
            if (elapsed - lastUpdate >= 15) {
              lastUpdate = elapsed;
            
              for (int j = 0; j < groupSize; j++) {
                if (movements[j].active) {
                  if (movements[j].useInterpolation) {
                    float progress = float(elapsed) / movements[j].duration;
                  
                    if (progress >= 1.0) {
                      servos[movements[j].servoIndex].write(movements[j].targetAngle);
                      movements[j].active = false;
                    } else {
                      int angle = movements[j].startAngle + 
                                 (movements[j].targetAngle - movements[j].startAngle) * progress;
                      servos[movements[j].servoIndex].write(angle);
                    }
                  } else {
                    // Natural step inside an interpolated group: snap and deactivate
                    servos[movements[j].servoIndex].write(movements[j].targetAngle);
                    movements[j].active = false;
                  }
                }
              }
            }
            cancellableDelay(1);
          }
          
          // Ensure every servo has reached its exact target
          for (int j = 0; j < groupSize; j++) {
            servos[movements[j].servoIndex].write(movements[j].targetAngle);
          }
          
          Serial.println("Synchronised mixed group complete.");          
        }

        cancellableDelay(finalPause);
        if (newCommand) return;

        i = groupEnd;
      }
    }

    loopNum++;
    Serial.println("Loop iteration: " + String(loopNum));
  } while (cmd.repeat && !newCommand);
  Serial.println("Command execution complete.");
}

// ---------------------------------------------------------------------------
// Setup & main loop
// ---------------------------------------------------------------------------

void setup(){
  Serial.begin(9600);

  radio.begin();
  radio.openReadingPipe(0, address);
  radio.setChannel(110);
  radio.setCRCLength(RF24_CRC_16);
  radio.setAutoAck(true);
  radio.setDataRate(RF24_250KBPS);
  radio.setPALevel(RF24_PA_LOW);
  radio.startListening();

  for (int i = 0; i < NUM_SERVOS; i++){
    servos[i].attach(servoPins[i]);
    servos[i].write(0);
  }

  Serial.println("System ready.");
}

void loop(){
  if (radio.available()) {
    Serial.println("Receiving data...");
    char text[32] = {0};
    radio.read(&text, sizeof(text));
    
    int firstNum = 0, secondNum = 0;
    sscanf(text, "%d,%d", &firstNum, &secondNum);

    int receivedNumber = USE_FIRST ? firstNum : secondNum;

    if (receivedNumber >= 0 && receivedNumber <= 6){
      Serial.print("Command received: ");
      Serial.println(receivedNumber);
      currentCommand = receivedNumber;
      newCommand = true;
    }
  }

  if (newCommand && currentCommand != -1){
    newCommand = false;
    executeCommand(currentCommand);
  }
}

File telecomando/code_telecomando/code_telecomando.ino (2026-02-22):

/** 
 * @file    code_telecomando.ino
 * @brief   Remote controller firmware for the "Nato Due Volte" carnival float
 *          (73rd edition of the Carnevale di Massafra).
 *
 * This sketch runs on a custom Arduino Nano shield and handles input from
 * seven physical buttons. Button presses are transmitted wirelessly via
 * the nRF24L01+ module to two independent control units, each driving a
 * scenic robotic hand (5 servo motors per hand).
 *
 * Communication protocol:
 *   A command is composed of two sequential button presses sent as a
 *   comma-separated string "firstButton,secondButton" (e.g. "0,3").
 *   The first press selects the command for controller #1 (USE_FIRST = true),
 *   the second press selects the command for controller #2 (USE_FIRST = false).
 *   A 2-second timeout resets the sequence if the second press is not received.
 *
 * Hardware:
 *   - Arduino Nano (on custom shield)
 *   - nRF24L01+ transceiver module
 *   - 7 push buttons (indexed 0–6, left to right, top to bottom)
 *
 * Dependencies:
 *   - RF24 library (available via Arduino IDE Library Manager)
 */

#include <SPI.h>
#include <nRF24L01.h>
#include <RF24.h>

#define CE_PIN 9
#define CSN_PIN 10
RF24 radio(CE_PIN, CSN_PIN);
const byte address[6] = "00001";

#define NUM_BUTTONS 7
int buttonPins[NUM_BUTTONS] = {2, 3, 4, 5, 6, 7, 8};

int lastState[NUM_BUTTONS];

int firstPressed = -1;
unsigned long firstPressTime = 0;
const unsigned long TIMEOUT = 2000; // ms - max interval between the two button presses

void setup() {
  Serial.begin(9600);
  
  for (int i = 0; i < NUM_BUTTONS; i++) {
    pinMode(buttonPins[i], INPUT);
    lastState[i] = LOW; // initial state: not pressed
  }

  radio.begin();
  radio.openWritingPipe(address);
  radio.setDataRate(RF24_250KBPS);
  radio.setChannel(110);
  radio.setCRCLength(RF24_CRC_16);
  radio.setAutoAck(true);
  radio.setRetries(5, 15);
  radio.setPALevel(RF24_PA_LOW);
  radio.stopListening(); // transmit mode

  Serial.println("Remote controller ready.");
}

void loop() {
  // Reset first press if timeout has elapsed
  if (firstPressed != -1 && (millis() - firstPressTime > TIMEOUT)){
    Serial.println("Timeout: first press reset.");
    firstPressed = -1;
  }

  for (int i = 0; i < NUM_BUTTONS; i++) {
    int state = digitalRead(buttonPins[i]);

    // Rising edge detected (button just pressed)
    if (state == HIGH && lastState[i] == LOW) {
      if (firstPressed == -1){
        // Record first press
        firstPressed = i;
        firstPressTime = millis();
        Serial.print("First press: button ");
        Serial.println(i);
      } else {
        // Second press: build and transmit command string
        char message[16];
        snprintf(message, sizeof(message), "%d,%d", firstPressed, i);
        radio.write(&message, sizeof(message));
        Serial.print("Command sent: ");
        Serial.println(message);

        firstPressed = -1; // reset for next command
      }
      delay(200); // debounce
    }
    lastState[i] = state;
  }
}
